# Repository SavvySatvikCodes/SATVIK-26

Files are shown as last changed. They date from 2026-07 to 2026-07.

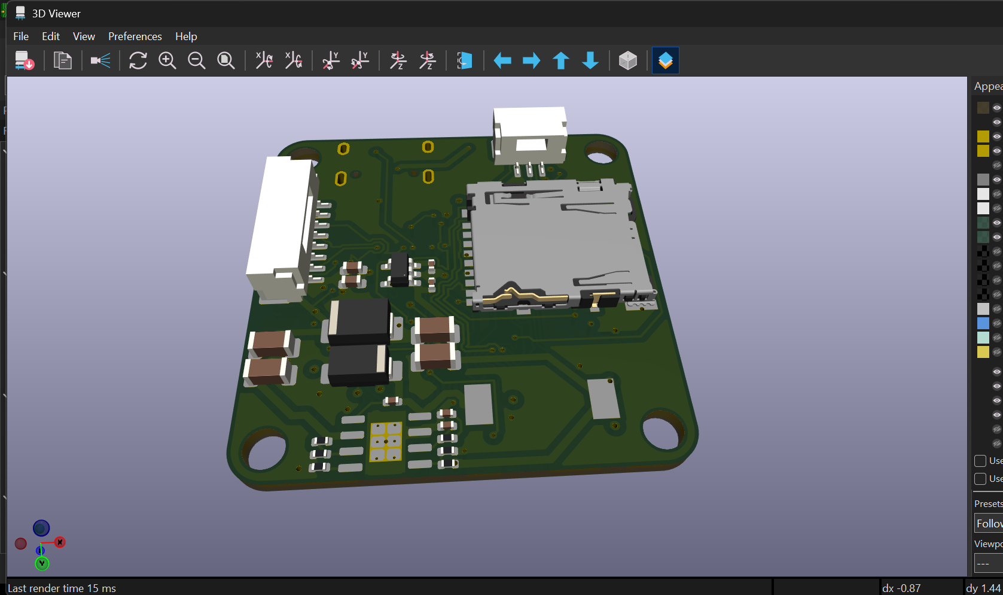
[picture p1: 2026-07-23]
hardware/Screenshot 2026-07-23 163646.png

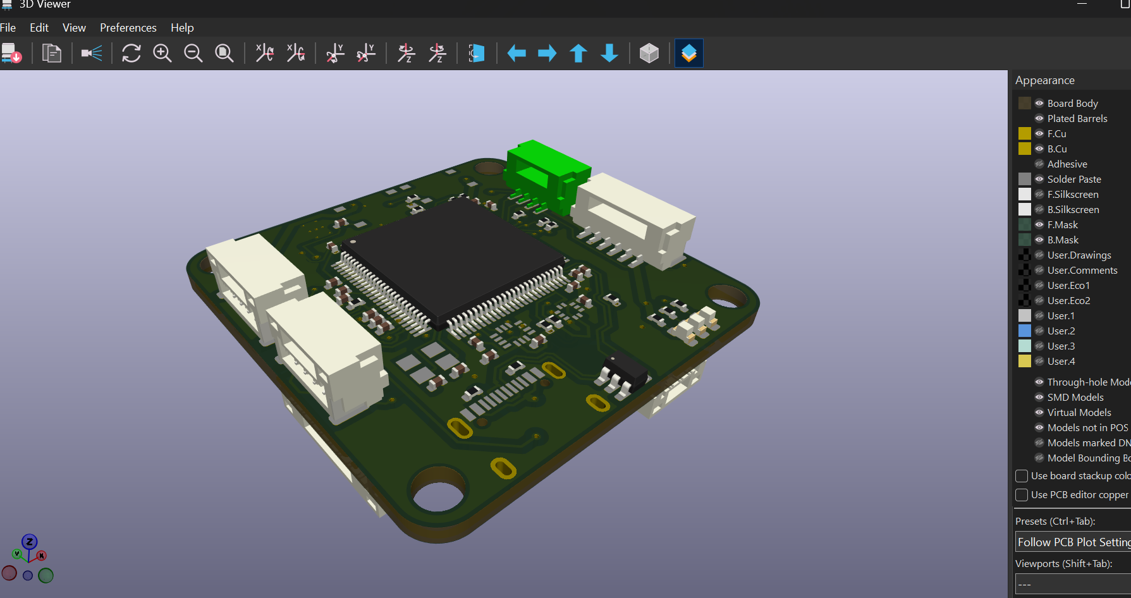
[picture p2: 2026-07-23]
hardware/Screenshot 2026-07-23 163654.png

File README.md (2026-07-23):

# SATVIK-26

**A custom STM32H743 flight controller, designed from scratch for ArduPilot.**

36 × 36 mm, 30.5 mm stack mounting, 4-layer. My first PCB, built for Hack Club Macondo.

---
## What this is

SATVIK-26 is a flight controller: the computer that reads a drone's sensors and decides how fast to spin each motor. It runs [ArduPilot](https://ardupilot.org/) on an STM32H743VIT6, a 480 MHz Cortex-M7.

Anyone can just buy a flight controller and assemble a drone, but I wanted to understand one. There is a large gap between knowing that an IMU talks over Serial Peripheral Interface contrast to having placed that IMU's decoupling capacitor yourself, knowing why it sits exactly where it sits. The only way I know to cross that gap is to draw the schematic and route the board.

This repo is the complete hardware design: schematic, layout, gerbers, BOM, and the reasoning behind the decisions.

---
## Specifications

- MCU - STM32H743VIT6, LQFP-100, 480 MHz Cortex-M7, 2 MB flash/1 MB RAM
- IMU	- ICM-42688-P (TDK InvenSense), SPI1
- Barometer - BMP388 (Bosch), I2C2
- Storage - microSD on SDMMC1 for onboard logging
- USB-C with USBLC6-2SC6 ESD protection, DFU accessible
- Input - 2 to 6S direct battery, SMBJ26A TVS clamp
- 5 V rail - TPS54560 buck, 15 µH inductor, SS56 catch diode
- 3.3 V rail - AP2112K-3.3 LDO from the 5 V rail
- Sensing - VBAT divider and ESC current sense into ADC1
- Motor outputs - 8 PWM channels
- Serial - 6 UARTs on JST-GH connectors
- Board - 36 × 36 mm, 4-layer FR4, 1.6 mm, 3 mm corner radius
- Mounting - 4 × M3 at 30.5 mm (standard FC stack)
- Components - 80 footprints, 55 top and 25 bottom
- Weight - 40 g

---
## What makes this not a copy

**Dual airframe, 8 PWM outputs.** Most 5-inch quad boards break out four motor outputs. I mapped eight timer channels to headers so the same board can fly a quad now and a fixed-wing later, where you need servo channels for ailerons, elevator and rudder on top of throttle. Four outputs would have made this a dead end. Eight cost me real routing space on a 36 mm board, and I decided the flexibility was worth it.

**FPV designed in, not bolted on.** A dedicated UART is broken out for a video transmitter, and the 5 V rail is sized with headroom to feed a camera and VTX rather than just flight electronics. Retrofitting FPV onto a board that never planned for it means splicing into power and hunting for a spare serial port.

**A custom ArduPilot hwdef.** ArduPilot does not know what is wired where on a board it has never seen. I am writing a `hwdef.dat` describing every peripheral, pin function and timer assignment, and the build system compiles firmware specifically for your hardware. That port is part of this project. The board is not finished until it boots real firmware.

For the record: Macondo's flight controller guide builds a **rocket** FC on a different MCU with a battery charger IC. This is a drone FC on an H7, no charger, different power tree, different sensors.

---
## Design decisions

- **TPS54560 buck, rated to 60V.** On 4S that looks like overkill, and cheaper 28 V parts would work. I took the headroom deliberately. 6S is 25.2 V charged, uncomfortably close to a 28 V absolute maximum, and a motor decelerating hard dumps energy back into the rail.
- **Entire power section moved to the back.** I could not route the board with everything on top. Rather than grow it to 40 × 40 and lose stack compatibility, the buck, inductor, LDO, filter caps and thirteen control passives all went to the bottom. That freed the top for MCU fanout, and it put the noisiest thing on the board on the opposite side of a solid ground plane from the IMU, crystal and USB pair. A space fix that turned out to be the right electrical call.
- **IMU as close to the mounting centroid as possible.** The further a sensor sits from the centre of rotation, the more frame vibration it reads as acceleration that is not real. Vibration is the most common cause of bad behaviour in custom ArduPilot builds.
- **Lower KV motors chosen on purpose.** 1855 KV instead of the common 2400 KV. Lower prop RPM means less vibration reaching an IMU sitting on a board I designed myself with no proven mounting. It is also more efficient, which buys flight time. 2400 KV would give roughly 9:1 thrust-to-weight, which is race-quad territory and pointless for a GPS platform flying Loiter and Auto. It also makes tuning the IMU harder.

---
## Stackup
Four layers: **F.Cu** signal, **In1.Cu** GND plane, **In2.Cu** +3V3 plane, **B.Cu** signal and power section.

+3V3 touches 38 pads spread across the whole board. The net that is everywhere gets the plane. VBAT_RAW became short traces, which is all a local 8-pad net needs.

---
## The work

The tidy version above is not how it felt.
Placing components looks like the easy part. It is not. Almost anything fits on a board if all you care about is fitting. I built layouts that passed every clearance check and were physically impossible to route, with pads jammed against the board edge and no path out at all. Each one had to be scrapped and rebuilt.

The final routing push ran **18 hours straight, 1pm on July 22nd to 6am on July 23rd, without a break.** By the end: 1114 track segments, 89 vias, zero unconnected pads.

Some NotSoFun blunders:
- The IMU had been deleted from the board entirely, and I had not noticed
- The crystal had been deleted too
- Thirteen buck and LDO support components stranded on the wrong side after the power flip, meaning a switching regulator's feedback network would have had to via across the board
- A netclass rule silently matching nothing, so every "power" trace was drawing at 0.2 mm instead of 0.6 mm

AND YES... after so much work it is quite nail-biting to put it on JLCPCB to see if your work actually computes... the real test is still far off 

---

## Things I got wrong

- **Connector pin order.** My connectors run 5V, GND, TX, RX. Most off-the-shelf GPS modules and telemetry radios use Pixhawk order with ground on the _last_ pin. Stock cables do not line up, and plugging one in without checking could push 5 V into a UART pin. Fixable by re-pinning cables, so the board still works as designed, but it is a genuine mistake and first on the rev 2 list. Every cable gets continuity-tested before it goes anywhere near power.
- **Thermal reliefs on the ground pours.** Ground connected to pads through four thin spokes, which exists to stop the plane wicking heat away during _hand_ soldering. On a dense board several pads could not fit the minimum spoke count. This board is reflow assembled, so thermal relief was simply the wrong setting. Switched to solid, which is better electrically and thermally.
- **Traces do not follow components.** Move a part after routing and the copper stays behind, silently disconnected. I found this out by doing it. Placement gets finished properly before routing starts.

---
## What I would do differently

- **Stop designing version one like it is the last version.** Most of my pain came from trying to make the first board complete instead of making it _work_. A first revision exists to prove the core design is sound and to teach you what you got wrong. Every extra feature is another thing that can be wrong, and another thing you have to route.
- **Smaller connectors.** JST-GH is the right professional choice and it is what real flight controllers use, but it is physically large and it ate a serious amount of board edge and routing space on a 36 mm board. On a first iteration I would take something more compact, or simply break out fewer UARTs.
- **Skip the gimmicks.** Status LEDs and their resistors, extra headers, nice-to-haves. None of them made the board work. All of them competed for space against things that did.
- **Plan the escape routes before finalizing placement.** The lesson that cost the most time. A component is not placed correctly just because it fits and clears its neighbours. It is placed correctly when every one of its pads has a realistic path to where it needs to go.

---
## Airframe and flight dynamics

| Item | Mass |
| --- | --- |
| 5-inch carbon frame | 120 g |
| 4 × 2207 motors | 132 g |
| 4-in-1 ESC | 14 g |
| SATVIK-26 FC | 40 g |
| GPS, compass, mast | 18 g |
| RC receiver | 15 g |
| Telemetry radio (air) | 15 g |
| Propellers | 18 g |
| Wiring, standoffs, hardware | 35 g |
| **Dry** | **407 g**  |
| 4S 1850 mAh LiPo | 244 g |
| **All-up weight** | **~651 g** |
| | |
___
## Airframe parts

| Part | Chosen component |
| --- | --- |
| Frame | TBS Source One V6, 5 inch |
| Motors | iFlight XING2 2207 1855 KV (×4) |
| ESC | Sequre Blueson A2 6S 65A, AM32 |
| Propellers | Gemfan 51466 tri-blade, 5 inch |
| GPS and compass | Sequre M10-252Q with QMC5883 |
| Telemetry | Micoair 915 MHz LoRa pair |
| RC link | FlySky FS-i6X with FS-iA6B receiver |
| Battery | GNB 1850 mAh 4S 120C, XT60 (×2) |
| FC mounting | Rubber or TPU soft mounts |
With XING2 2207 1855 KV motors on 4S: roughly **6.8:1 thrust-to-weight**, hover throttle around **38 %**, estimated **5-8 minutes** of mixed GPS flying.

---
## Status

- [x] Schematic complete, ERC clean
- [x] Component placement
- [x] 4-layer routing complete, 0 unconnected pads
- [x] DRC clean
- [x] Gerbers verified in JLCPCB's viewer
- [x] BOM and pick-and-place prepared
- [ ] Boards ordered
- [ ] ArduPilot `hwdef` written and firmware compiled
- [ ] Bring-up
- [ ] Airframe assembly
- [ ] Maiden hover
- [ ] Loiter and Auto missions

**Bring-up is planned in order:** visual inspection, then a current-limited bench supply with the limit set low, then every rail verified with a multimeter before a battery touches the board, then USB enumeration and DFU, then flash ArduPilot, then confirm each peripheral in Mission Planner one at a time. Motors tested with **propellers removed**.

---
## Regulatory
Over 250 g, so under Transport Canada rules this must be registered and flown by a certified pilot. That means you (& I) am taking the Small Basic Exam and registering the aircraft.

Basic certification allows uncontrolled (Class G) airspace only, 30 m from bystanders, below 400 ft, within visual line of sight. Most of Toronto is controlled airspace, which needs Advanced certification and a manufacturer safety-assurance declaration, something a homebuilt aircraft cannot obtain by definition. So fly out of city, many apps show you the proper zones.

---
## Tools

**[KiCad 10](https://www.kicad.org/)** for schematic and layout. **[STM32CubeMX](https://www.st.com/en/development-tools/stm32cubemx.html)** for pin mapping. [**ArduPilot**](https://ardupilot.org/) as target firmware, with SITL for development during parts lead time. **[JLCPCB](https://jlcpcb.com/)** for 4-layer fabrication and assembly.

---
CREDITS TO [OBSIDIAN](https://obsidian.md/), an .md file editor and notes taking app, for easing the process of writing in this file format.

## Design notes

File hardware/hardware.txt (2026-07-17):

Configuration	hardware
STM32CubeMX 	6.18.0
Date	07/16/2026
MCU	STM32H743VITx

PERIPHERALS	MODES	FUNCTIONS	PINS
ADC1	IN10 Single-ended	ADC1_INP10	PC0
ADC1	IN11 Single-ended	ADC1_INP11	PC1
I2C2	I2C	I2C2_SCL	PB10
I2C2	I2C	I2C2_SDA	PB11
RCC	Crystal/Ceramic Resonator	RCC_OSC_IN	PH0-OSC_IN (PH0)
RCC	Crystal/Ceramic Resonator	RCC_OSC_OUT	PH1-OSC_OUT (PH1)
SDMMC1	SD 4 bits Wide bus	SDMMC1_CK	PC12
SDMMC1	SD 4 bits Wide bus	SDMMC1_CMD	PD2
SDMMC1	SD 4 bits Wide bus	SDMMC1_D0	PC8
SDMMC1	SD 4 bits Wide bus	SDMMC1_D1	PC9
SDMMC1	SD 4 bits Wide bus	SDMMC1_D2	PC10
SDMMC1	SD 4 bits Wide bus	SDMMC1_D3	PC11
SPI1	Full-Duplex Master	SPI1_MISO	PA6
SPI1	Full-Duplex Master	SPI1_MOSI	PA7
SPI1	Full-Duplex Master	SPI1_SCK	PA5
SYS	SysTick	SYS_VS_Systick	VP_SYS_VS_Systick
TIM3	PWM Generation CH3	TIM3_CH3	PB0
TIM3	PWM Generation CH4	TIM3_CH4	PB1
TIM5	PWM Generation CH1	TIM5_CH1	PA0
TIM5	PWM Generation CH2	TIM5_CH2	PA1
UART4	Asynchronous	UART4_RX	PB8
UART4	Asynchronous	UART4_TX	PB9
UART7	Asynchronous	UART7_RX	PE7
UART7	Asynchronous	UART7_TX	PE8
USART1	Asynchronous	USART1_RX	PA10
USART1	Asynchronous	USART1_TX	PA9
USART2	Asynchronous	USART2_RX	PD6
USART2	Asynchronous	USART2_TX	PD5
USART6	Asynchronous	USART6_RX	PC7
USART6	Asynchronous	USART6_TX	PC6
USB_OTG_FS	Device_Only	USB_OTG_FS_DM	PA11
USB_OTG_FS	Device_Only	USB_OTG_FS_DP	PA12

Pin Nb	PINs	FUNCTIONs	LABELs
9	PC15-OSC32_OUT (OSC32_OUT)	GPIO_Output	
12	PH0-OSC_IN (PH0)	RCC_OSC_IN	
13	PH1-OSC_OUT (PH1)	RCC_OSC_OUT	
15	PC0	ADC1_INP10	
16	PC1	ADC1_INP11	
22	PA0	TIM5_CH1	
23	PA1	TIM5_CH2	
29	PA5	SPI1_SCK	
30	PA6	SPI1_MISO	
31	PA7	SPI1_MOSI	
34	PB0	TIM3_CH3	
35	PB1	TIM3_CH4	
37	PE7	UART7_RX	
38	PE8	UART7_TX	
46	PB10	I2C2_SCL	
47	PB11	I2C2_SDA	
63	PC6	USART6_TX	
64	PC7	USART6_RX	
65	PC8	SDMMC1_D0	
66	PC9	SDMMC1_D1	
68	PA9	USART1_TX	
69	PA10	USART1_RX	
70	PA11	USB_OTG_FS_DM	
71	PA12	USB_OTG_FS_DP	
72	PA13 (JTMS/SWDIO)*	DEBUG_JTMS-SWDIO	
76	PA14 (JTCK/SWCLK)*	DEBUG_JTCK-SWCLK	
78	PC10	SDMMC1_D2	
79	PC11	SDMMC1_D3	
80	PC12	SDMMC1_CK	
83	PD2	SDMMC1_CMD	
86	PD5	USART2_TX	
87	PD6	USART2_RX	
95	PB8	UART4_RX	
96	PB9	UART4_TX	
PERIPHERALS	MODES	FUNCTIONS	PINS
ADC1	IN10 Single-ended	ADC1_INP10	PC0
ADC1	IN11 Single-ended	ADC1_INP11	PC1
I2C2	I2C	I2C2_SCL	PB10
I2C2	I2C	I2C2_SDA	PB11
RCC	Crystal/Ceramic Resonator	RCC_OSC_IN	PH0-OSC_IN (PH0)
RCC	Crystal/Ceramic Resonator	RCC_OSC_OUT	PH1-OSC_OUT (PH1)
SDMMC1	SD 4 bits Wide bus	SDMMC1_CK	PC12
SDMMC1	SD 4 bits Wide bus	SDMMC1_CMD	PD2
SDMMC1	SD 4 bits Wide bus	SDMMC1_D0	PC8
SDMMC1	SD 4 bits Wide bus	SDMMC1_D1	PC9
SDMMC1	SD 4 bits Wide bus	SDMMC1_D2	PC10
SDMMC1	SD 4 bits Wide bus	SDMMC1_D3	PC11
SPI1	Full-Duplex Master	SPI1_MISO	PA6
SPI1	Full-Duplex Master	SPI1_MOSI	PA7
SPI1	Full-Duplex Master	SPI1_SCK	PA5
SYS	SysTick	SYS_VS_Systick	VP_SYS_VS_Systick
TIM3	PWM Generation CH3	TIM3_CH3	PB0
TIM3	PWM Generation CH4	TIM3_CH4	PB1
TIM5	PWM Generation CH1	TIM5_CH1	PA0
TIM5	PWM Generation CH2	TIM5_CH2	PA1
UART4	Asynchronous	UART4_RX	PB8
UART4	Asynchronous	UART4_TX	PB9
UART7	Asynchronous	UART7_RX	PE7
UART7	Asynchronous	UART7_TX	PE8
USART1	Asynchronous	USART1_RX	PA10
USART1	Asynchronous	USART1_TX	PA9
USART2	Asynchronous	USART2_RX	PD6
USART2	Asynchronous	USART2_TX	PD5
USART6	Asynchronous	USART6_RX	PC7
USART6	Asynchronous	USART6_TX	PC6
USB_OTG_FS	Device_Only	USB_OTG_FS_DM	PA11
USB_OTG_FS	Device_Only	USB_OTG_FS_DP	PA12

Pin Nb	PINs	FUNCTIONs	LABELs
9	PC15-OSC32_OUT (OSC32_OUT)	GPIO_Output	
12	PH0-OSC_IN (PH0)	RCC_OSC_IN	
13	PH1-OSC_OUT (PH1)	RCC_OSC_OUT	
15	PC0	ADC1_INP10	
16	PC1	ADC1_INP11	
22	PA0	TIM5_CH1	
23	PA1	TIM5_CH2	
29	PA5	SPI1_SCK	
30	PA6	SPI1_MISO	
31	PA7	SPI1_MOSI	
34	PB0	TIM3_CH3	
35	PB1	TIM3_CH4	
37	PE7	UART7_RX	
38	PE8	UART7_TX	
46	PB10	I2C2_SCL	
47	PB11	I2C2_SDA	
63	PC6	USART6_TX	
64	PC7	USART6_RX	
65	PC8	SDMMC1_D0	
66	PC9	SDMMC1_D1	
68	PA9	USART1_TX	
69	PA10	USART1_RX	
70	PA11	USB_OTG_FS_DM	
71	PA12	USB_OTG_FS_DP	
72	PA13 (JTMS/SWDIO)*	DEBUG_JTMS-SWDIO	
76	PA14 (JTCK/SWCLK)*	DEBUG_JTCK-SWCLK	
78	PC10	SDMMC1_D2	
79	PC11	SDMMC1_D3	
80	PC12	SDMMC1_CK	
83	PD2	SDMMC1_CMD	
86	PD5	USART2_TX	
87	PD6	USART2_RX	
95	PB8	UART4_RX	
96	PB9	UART4_TX	

SOFTWARE PROJECT

Project Settings : 
Project Name : hardware
Project Folder : C:\Users\gargs\Desktop\SavvyVenv\GITTY\SATVIK-26\hardware
Toolchain / IDE : EWARM V8.50
Firmware Package Name and Version : STM32Cube FW_H7 V1.13.0

Code Generation Settings : 
STM32Cube MCU packages and embedded software packs : Copy all used libraries into the project folder
Generate peripheral initialization as a pair of '.c/.h' files per peripheral : No
Backup previously generated files when re-generating : No
Delete previously generated files when not re-generated : Yes
Set all free pins as analog (to optimize the power consumption) : No

Toolchains Settings : 
Compiler Optimizations :

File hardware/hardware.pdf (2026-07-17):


16/07/2026

hardware Project
Configuration Report

## 1. Description

### 1.1. Project

Project Name | hardware
Board Name | custom
Generated with: | STM32CubeMX 6.18.0
Date | 07/16/2026

### 1.2. MCU

MCU Series | STM32H7
MCU Line | STM32H743/753
MCU name | STM32H743VITx
MCU Package | LQFP100
MCU Pin number | 100

### 1.3. Core(s) information

Core(s) | ARM Cortex-M7

## 2. Pinout Configuration

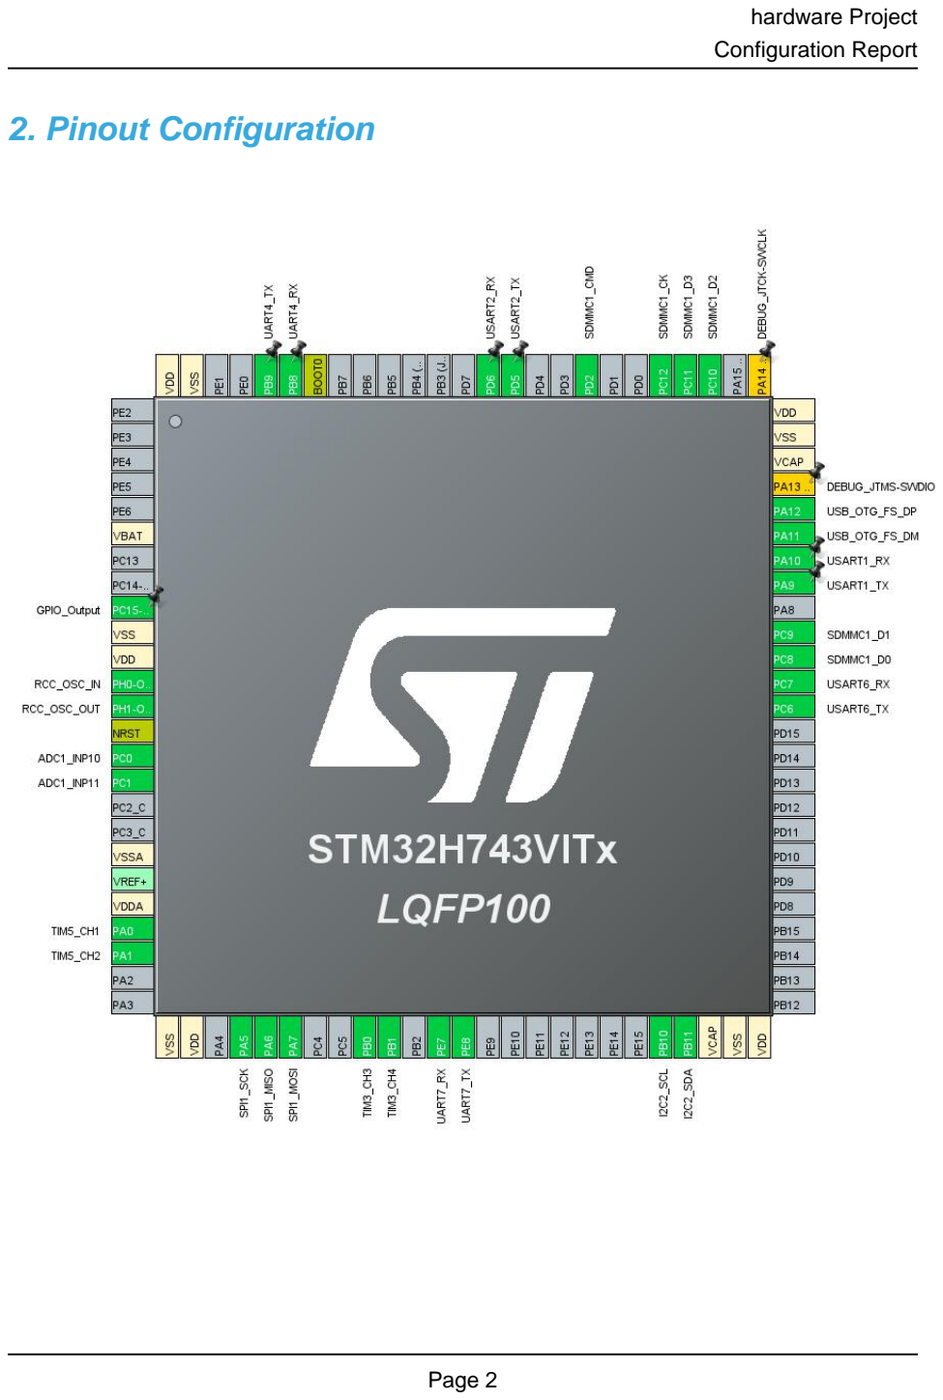
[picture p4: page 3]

## 3. Pins Configuration

Pin Number LQFP100 | Pin Name (function after reset) | Pin Type | Alternate Function(s) | Label
6 | VBAT | Power
9 | PC15-OSC32_OUT (OSC32_OUT) * | I/O | GPIO_Output
10 | VSS | Power
11 | VDD | Power
12 | PH0-OSC_IN (PH0) | I/O | RCC_OSC_IN
13 | PH1-OSC_OUT (PH1) | I/O | RCC_OSC_OUT
14 | NRST | Reset
15 | PC0 | I/O | ADC1_INP10
16 | PC1 | I/O | ADC1_INP11
19 | VSSA | Power
21 | VDDA | Power
22 | PA0 | I/O | TIM5_CH1
23 | PA1 | I/O | TIM5_CH2
26 | VSS | Power
27 | VDD | Power
29 | PA5 | I/O | SPI1_SCK
30 | PA6 | I/O | SPI1_MISO
31 | PA7 | I/O | SPI1_MOSI
34 | PB0 | I/O | TIM3_CH3
35 | PB1 | I/O | TIM3_CH4
37 | PE7 | I/O | UART7_RX
38 | PE8 | I/O | UART7_TX
46 | PB10 | I/O | I2C2_SCL
47 | PB11 | I/O | I2C2_SDA
48 | VCAP | Power
49 | VSS | Power
50 | VDD | Power
63 | PC6 | I/O | USART6_TX
64 | PC7 | I/O | USART6_RX
65 | PC8 | I/O | SDMMC1_D0
66 | PC9 | I/O | SDMMC1_D1
68 | PA9 | I/O | USART1_TX
69 | PA10 | I/O | USART1_RX
70 | PA11 | I/O | USB_OTG_FS_DM
71 | PA12 | I/O | USB_OTG_FS_DP

Pin Number LQFP100 | Pin Name (function after reset) | Pin Type | Alternate Function(s) | Label
72 | PA13 (JTMS/SWDIO) ** | I/O | DEBUG_JTMS-SWDIO
73 | VCAP | Power
74 | VSS | Power
75 | VDD | Power
76 | PA14 (JTCK/SWCLK) ** | I/O | DEBUG_JTCK-SWCLK
78 | PC10 | I/O | SDMMC1_D2
79 | PC11 | I/O | SDMMC1_D3
80 | PC12 | I/O | SDMMC1_CK
83 | PD2 | I/O | SDMMC1_CMD
86 | PD5 | I/O | USART2_TX
87 | PD6 | I/O | USART2_RX
94 | BOOT0 | Boot
95 | PB8 | I/O | UART4_RX
96 | PB9 | I/O | UART4_TX
99 | VSS | Power
100 | VDD | Power

* The pin is affected with an I/O function
** The pin is affected with a peripheral function but no peripheral mode is activated

## 4. Clock Tree Configuration

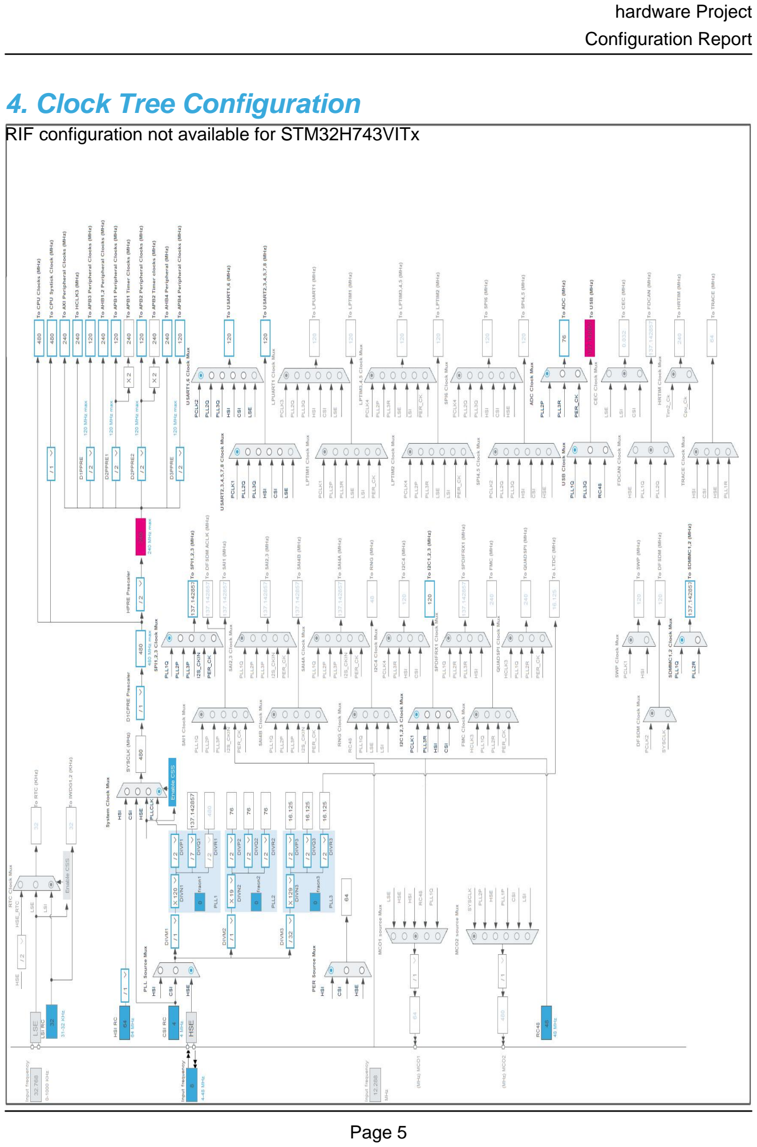
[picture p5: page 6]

RIF configuration not available for STM32H743VITx

## 1. Power Consumption Calculator report

### 1.1. Microcontroller Selection

Series | STM32H7
Line | STM32H743/753
MCU | STM32H743VITx
Datasheet | DS12110_Rev8

### 1.2. Parameter Selection

Temperature | 25
Vdd | 3.0

### 1.3. Battery Selection

Battery | Alkaline(9V)
Capacity | 625.0 mAh
Self Discharge | 0.3 %/month
Nominal Voltage | 9.0 V
Max Cont Current | 200.0 mA
Max Pulse Current | 0.0 mA
Cells in series | 1
Cells in parallel | 1

### 1.4. Sequence

Step | Step1 | Step2
Mode | RUN | STOP
Vdd | 3.0 | 3.0
Voltage Source | Battery | Battery
Range | VOS0: Scale0-High | SVOS5: System-Scale5
D1 Mode | DRUN/CRUN | DSTANDBY
D2 Mode | DRUN | DSTANDBY
D3 Mode | DRUN | DSTOP
Fetch Type | ITCM | NA
CPU Frequency | 480 MHz | 0 Hz
Clock Configuration | HSE BYP PLL | Flash-OFF
Clock Source Frequency | 24 MHz | 0 Hz
Peripherals
Additional Cons. | 0 mA | 0 mA
Average Current | 148 mA | 150 µA
Duration | 0.1 ms | 0.9 ms
DMIPS | 1027.0 | 0.0
Ta Max | 105.02 | 124.98
Category | In DS Table | In DS Table

### 1.5. Results

Sequence Time | 1 ms | Average Current | 14.94 mA
Battery Life | 1 day, 17 hours | Average DMIPS | 1027.2001 DMIPS

### 1.6. Chart

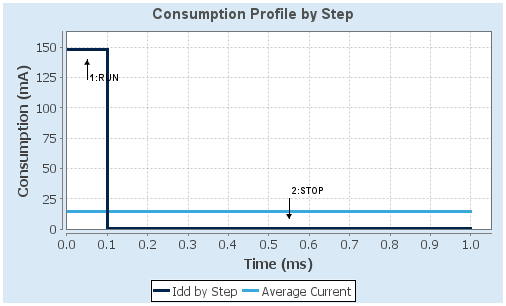
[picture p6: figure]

## 2. Software Project

### 2.1. Project Settings

Name | Value
Project Name | hardware
Project Folder | C:\Users\gargs\Desktop\SavvyVenv\GITTY\SATVIK-26\hardware
Toolchain / IDE | EWARM V8.50
Firmware Package Name and Version | STM32Cube FW_H7 V1.13.0
Application Structure | Advanced
Generate Under Root | No
Do not generate the main() | No
Minimum Heap Size | 0x200
Minimum Stack Size | 0x400

### 2.2. Code Generation Settings

Name | Value
STM32Cube MCU packages and embedded software | Copy all used libraries into the project folder
Generate peripheral initialization as a pair of '.c/.h' files | No
Backup previously generated files when re-generating | No
Keep User Code when re-generating | Yes
Delete previously generated files when not re-generated | Yes
Set all free pins as analog (to optimize the power consumption) | No
Enable Full Assert | No

### 2.3. Advanced Settings - Generated Function Calls

Rank | Function Name | Peripheral Instance Name
1 | SystemClock_Config | RCC
2 | MX_GPIO_Init | GPIO
3 | MX_SPI1_Init | SPI1
4 | MX_USB_OTG_FS_PCD_Init | USB_OTG_FS
5 | MX_ADC1_Init | ADC1
6 | MX_I2C2_Init | I2C2
7 | MX_SDMMC1_SD_Init | SDMMC1
8 | MX_TIM3_Init | TIM3
9 | MX_TIM5_Init | TIM5
10 | MX_UART4_Init | UART4
11 | MX_UART7_Init | UART7

Rank | Function Name | Peripheral Instance Name
12 | MX_USART1_UART_Init | USART1
13 | MX_USART2_UART_Init | USART2
14 | MX_USART6_UART_Init | USART6

## 3. Peripherals and Middlewares Configuration

### 3.1. ADC1

IN10: IN10 Single-ended
mode: IN11
3.1.1. Parameter Settings:

ADCs_Common_Settings:

Mode | Independent mode
ADC_Settings:
Clock Prescaler | Asynchronous clock mode divided by 1
Resolution | ADC 16-bit resolution
Scan Conversion Mode | Disabled
Continuous Conversion Mode | Disabled
Discontinuous Conversion Mode | Disabled
End Of Conversion Selection | End of single conversion
Overrun behaviour | Overrun data preserved
Left Bit Shift | No bit shift
Conversion Data Management Mode | Regular Conversion data stored in DR register only
Low Power Auto Wait | Disabled
ADC_Regular_ConversionMode:
Enable Regular Conversions | Enable
Enable Regular Oversampling | Disable
Oversampling Ratio | 1
Number Of Conversion | 1
External Trigger Conversion Source | Regular Conversion launched by software
External Trigger Conversion Edge | None
Rank | 1
Channel | Channel 10
Sampling Time | 1.5 Cycles
Offset Number | No offset
Offset Signed Saturation | Disable
ADC_Injected_ConversionMode:
Enable Injected Conversions | Disable
Analog Watchdog 1:
Enable Analog WatchDog1 Mode | false
Analog Watchdog 2:
Enable Analog WatchDog2 Mode | false
Analog Watchdog 3:
Enable Analog WatchDog3 Mode | false

### 3.2. CORTEX_M7

3.2.1. Parameter Settings:

Speculation default mode Settings:

Speculation default mode | Enabled *
Cortex Interface Settings:
CPU ICache | Disabled
CPU DCache | Disabled
Cortex Memory Protection Unit Control Settings:
MPU Control Mode | Background Region Privileged accesses only + MPU Disabled during hard fault, NMI and FAULTMASK handlers

Cortex Memory Protection Unit Region 0 Settings:

MPU Region | Enabled
MPU Region Base Address | 0x0 *
MPU Region Size | 4GB
MPU SubRegion Disable | 0x87 *
MPU TEX field level | level 0
MPU Access Permission | ALL ACCESS NOT PERMITTED
MPU Instruction Access | DISABLE
MPU Shareability Permission | ENABLE
MPU Cacheable Permission | DISABLE
MPU Bufferable Permission | DISABLE
Cortex Memory Protection Unit Region 1 Settings:
MPU Region | Disabled
Cortex Memory Protection Unit Region 2 Settings:
MPU Region | Disabled
Cortex Memory Protection Unit Region 3 Settings:
MPU Region | Disabled
Cortex Memory Protection Unit Region 4 Settings:
MPU Region | Disabled
Cortex Memory Protection Unit Region 5 Settings:
MPU Region | Disabled
Cortex Memory Protection Unit Region 6 Settings:
MPU Region | Disabled
Cortex Memory Protection Unit Region 7 Settings:
MPU Region | Disabled
Cortex Memory Protection Unit Region 8 Settings:

MPU Region | Disabled
Cortex Memory Protection Unit Region 9 Settings:
MPU Region | Disabled
Cortex Memory Protection Unit Region 10 Settings:
MPU Region | Disabled
Cortex Memory Protection Unit Region 11 Settings:
MPU Region | Disabled
Cortex Memory Protection Unit Region 12 Settings:
MPU Region | Disabled
Cortex Memory Protection Unit Region 13 Settings:
MPU Region | Disabled
Cortex Memory Protection Unit Region 14 Settings:
MPU Region | Disabled
Cortex Memory Protection Unit Region 15 Settings:
MPU Region | Disabled

### 3.3. I2C2

I2C: I2C
3.3.1. Parameter Settings:

Timing configuration:

Custom Timing | Disabled
I2C Speed Mode | Standard Mode
I2C Speed Frequency (KHz) | 100
Rise Time (ns) | 0
Fall Time (ns) | 0
Coefficient of Digital Filter | 0
Analog Filter | Enabled
Timing | 0x307075B1 *
Slave Features:
Clock No Stretch Mode | Disabled
General Call Address Detection | Disabled
Primary Address Length selection | 7-bit
Dual Address Acknowledged | Disabled
Primary slave address | 0

### 3.4. MEMORYMAP

mode: Activated

### 3.5. RCC

High Speed Clock (HSE): Crystal/Ceramic Resonator
3.5.1. Parameter Settings:

Power Parameters:

SupplySource | PWR_LDO_SUPPLY
Power Regulator Voltage Scale | Power Regulator Voltage Scale 0
RCC Parameters:
TIM Prescaler Selection | Disabled
HSE Startup Timout Value (ms) | 100
LSE Startup Timout Value (ms) | 5000
CSI Calibration Value | 32
HSI Calibration Value | 64
System Parameters:
VDD voltage (V) | 3.3
Flash Latency(WS) | 4 WS (5 CPU cycle)
Product revision | rev.V
PLL range Parameters:
PLL1 clock Input range | Between 8 and 16 MHz
PLL2 input frequency range | Between 8 and 16 MHz
PLL1 clock Output range | Wide VCO range
PLL2 clock Output range | MEDIUM VCO range

### 3.6. SDMMC1

Mode: SD 4 bits Wide bus
3.6.1. Parameter Settings:

SDMMC parameters:

Clock transition on which the bit capture is made | Rising transition
SDMMC Clock output enable when the bus is idle | Disable the power save for the clock
SDMMC hardware flow control | The hardware control flow is disabled
SDMMC clock divide factor | 0
Is external transceiver present ? | no

### 3.7. SPI1

Mode: Full-Duplex Master
3.7.1. Parameter Settings:

Basic Parameters:

Frame Format | Motorola
Data Size | 4 Bits
First Bit | MSB First
Clock Parameters:
Prescaler (for Baud Rate) | 2
Baud Rate | 68.57143 MBits/s *
Clock Polarity (CPOL) | Low
Clock Phase (CPHA) | 1 Edge
Advanced Parameters:
CRC Calculation | Disabled
NSSP Mode | Enabled
NSS Signal Type | Software
Fifo Threshold | Fifo Threshold 01 Data
Tx Crc Initialization Pattern | All Zero Pattern
Rx Crc Initialization Pattern | All Zero Pattern
Nss Polarity | Nss Polarity Low
Master Ss Idleness | 00 Cycle
Master Inter Data Idleness | 00 Cycle
Master Receiver Auto Susp | Disable
Master Keep Io State | Master Keep Io State Disable
IO Swap | Disabled

### 3.8. SYS

Timebase Source: SysTick

### 3.9. TIM3

Channel3: PWM Generation CH3 Channel4: PWM Generation CH4
3.9.1. Parameter Settings:

Counter Settings:

Prescaler (PSC - 16 bits value) | 0

Counter Mode | Up
Counter Period (AutoReload Register - 16 bits value ) | 65535
Internal Clock Division (CKD) | No Division
auto-reload preload | Disable
Trigger Output (TRGO) Parameters:
Master/Slave Mode (MSM bit) | Disable (Trigger input effect not delayed)
Trigger Event Selection TRGO | Reset (UG bit from TIMx_EGR)
Clear Input:
Clear Input Source | Disable
PWM Generation Channel 3:
Mode | PWM mode 1
Pulse (16 bits value) | 0
Output compare preload | Enable
Fast Mode | Disable
CH Polarity | High
PWM Generation Channel 4:
Mode | PWM mode 1
Pulse (16 bits value) | 0
Output compare preload | Enable
Fast Mode | Disable
CH Polarity | High

### 3.10. TIM5

Channel1: PWM Generation CH1 Channel2: PWM Generation CH2
3.10.1. Parameter Settings:

Counter Settings:

Prescaler (PSC - 16 bits value) | 0
Counter Mode | Up
Counter Period (AutoReload Register - 32 bits value ) | 4294967295
Internal Clock Division (CKD) | No Division
auto-reload preload | Disable
Trigger Output (TRGO) Parameters:
Master/Slave Mode (MSM bit) | Disable (Trigger input effect not delayed)
Trigger Event Selection TRGO | Reset (UG bit from TIMx_EGR)
Clear Input:
Clear Input Source | Disable
PWM Generation Channel 1:

Mode | PWM mode 1
Pulse (32 bits value) | 0
Output compare preload | Enable
Fast Mode | Disable
CH Polarity | High
PWM Generation Channel 2:
Mode | PWM mode 1
Pulse (32 bits value) | 0
Output compare preload | Enable
Fast Mode | Disable
CH Polarity | High

### 3.11. UART4

Mode: Asynchronous
3.11.1. Parameter Settings:

Basic Parameters:

Baud Rate | 115200
Word Length | 8 Bits (including Parity)
Parity | None
Stop Bits | 1
Advanced Parameters:
Data Direction | Receive and Transmit
Over Sampling | 16 Samples
Single Sample | Disable
ClockPrescaler | 1
Fifo Mode | FIFO mode disable
Txfifo Threshold | 1 eighth full configuration
Rxfifo Threshold | 1 eighth full configuration
Advanced Features:
Auto Baudrate | Disable
TX Pin Active Level Inversion | Disable
RX Pin Active Level Inversion | Disable
Data Inversion | Disable
TX and RX Pins Swapping | Disable
Overrun | Enable
DMA on RX Error | Enable
MSB First | Disable

### 3.12. UART7

Mode: Asynchronous
3.12.1. Parameter Settings:

Basic Parameters:

Baud Rate | 115200
Word Length | 8 Bits (including Parity)
Parity | None
Stop Bits | 1
Advanced Parameters:
Data Direction | Receive and Transmit
Over Sampling | 16 Samples
Single Sample | Disable
ClockPrescaler | 1
Fifo Mode | FIFO mode disable
Txfifo Threshold | 1 eighth full configuration
Rxfifo Threshold | 1 eighth full configuration
Advanced Features:
Auto Baudrate | Disable
TX Pin Active Level Inversion | Disable
RX Pin Active Level Inversion | Disable
Data Inversion | Disable
TX and RX Pins Swapping | Disable
Overrun | Enable
DMA on RX Error | Enable
MSB First | Disable

### 3.13. USART1

Mode: Asynchronous
3.13.1. Parameter Settings:

Basic Parameters:

Baud Rate | 115200
Word Length | 8 Bits (including Parity)
Parity | None
Stop Bits | 1
Advanced Parameters:
Data Direction | Receive and Transmit

Over Sampling | 16 Samples
Single Sample | Disable
ClockPrescaler | 1
Fifo Mode | Disable
Txfifo Threshold | 1 eighth full configuration
Rxfifo Threshold | 1 eighth full configuration
Advanced Features:
Auto Baudrate | Disable
TX Pin Active Level Inversion | Disable
RX Pin Active Level Inversion | Disable
Data Inversion | Disable
TX and RX Pins Swapping | Disable
Overrun | Enable
DMA on RX Error | Enable
MSB First | Disable

### 3.14. USART2

Mode: Asynchronous
3.14.1. Parameter Settings:

Basic Parameters:

Baud Rate | 115200
Word Length | 8 Bits (including Parity)
Parity | None
Stop Bits | 1
Advanced Parameters:
Data Direction | Receive and Transmit
Over Sampling | 16 Samples
Single Sample | Disable
ClockPrescaler | 1
Fifo Mode | Disable
Txfifo Threshold | 1 eighth full configuration
Rxfifo Threshold | 1 eighth full configuration
Advanced Features:
Auto Baudrate | Disable
TX Pin Active Level Inversion | Disable
RX Pin Active Level Inversion | Disable
Data Inversion | Disable
TX and RX Pins Swapping | Disable
Overrun | Enable

DMA on RX Error | Enable
MSB First | Disable

### 3.15. USART6

Mode: Asynchronous
3.15.1. Parameter Settings:

Basic Parameters:

Baud Rate | 115200
Word Length | 8 Bits (including Parity)
Parity | None
Stop Bits | 1
Advanced Parameters:
Data Direction | Receive and Transmit
Over Sampling | 16 Samples
Single Sample | Disable
ClockPrescaler | 1
Fifo Mode | Disable
Txfifo Threshold | 1 eighth full configuration
Rxfifo Threshold | 1 eighth full configuration
Advanced Features:
Auto Baudrate | Disable
TX Pin Active Level Inversion | Disable
RX Pin Active Level Inversion | Disable
Data Inversion | Disable
TX and RX Pins Swapping | Disable
Overrun | Enable
DMA on RX Error | Enable
MSB First | Disable

### 3.16. USB_OTG_FS

Mode: Device_Only
3.16.1. Parameter Settings:
Speed | Full Speed 12MBit/s
Enable internal IP DMA | Disabled
Low power | Disabled
Battery charging | Disabled

Link Power Management | Disabled
Use dedicated end point 1 interrupt | Disabled
VBUS sensing | Disabled
Signal start of frame | Disabled

* User modified value

## 4. System Configuration

### 4.1. GPIO configuration

IP | Pin | Signal | GPIO mode | GPIO pull/up pull down

Max
Speed

User Label

ADC1 | PC0 | ADC1_INP10 | Analog mode | No pull-up and no pull-down | n/a
| PC1 | ADC1_INP11 | Analog mode | No pull-up and no pull-down | n/a
I2C2 | PB10 | I2C2_SCL | Alternate Function Open Drain | No pull-up and no pull-down | Low
| PB11 | I2C2_SDA | Alternate Function Open Drain | No pull-up and no pull-down | Low
RCC | PH0- OSC_IN (PH0) | RCC_OSC_IN | n/a | n/a | n/a

PH1-
OSC_OUT
(PH1)
RCC_OSC_OUT | n/a | n/a | n/a
SDMMC1 | PC8 | SDMMC1_D0 | Alternate Function Push Pull | No pull-up and no pull-down | Very High
| PC9 | SDMMC1_D1 | Alternate Function Push Pull | No pull-up and no pull-down | Very High
| PC10 | SDMMC1_D2 | Alternate Function Push Pull | No pull-up and no pull-down | Very High
| PC11 | SDMMC1_D3 | Alternate Function Push Pull | No pull-up and no pull-down | Very High
PC12 | SDMMC1_CK Alternate Function Push Pull | No pull-up and no pull-down | Very High
PD2 | SDMMC1_CMD Alternate Function Push Pull | No pull-up and no pull-down | Very High
SPI1 | PA5 | SPI1_SCK | Alternate Function Push Pull | No pull-up and no pull-down | Low
| PA6 | SPI1_MISO | Alternate Function Push Pull | No pull-up and no pull-down | Low
| PA7 | SPI1_MOSI | Alternate Function Push Pull | No pull-up and no pull-down | Low
TIM3 | PB0 | TIM3_CH3 | Alternate Function Push Pull | No pull-up and no pull-down | Low
| PB1 | TIM3_CH4 | Alternate Function Push Pull | No pull-up and no pull-down | Low
TIM5 | PA0 | TIM5_CH1 | Alternate Function Push Pull | No pull-up and no pull-down | Low
| PA1 | TIM5_CH2 | Alternate Function Push Pull | No pull-up and no pull-down | Low
UART4 | PB8 | UART4_RX | Alternate Function Push Pull | No pull-up and no pull-down | Low
| PB9 | UART4_TX | Alternate Function Push Pull | No pull-up and no pull-down | Low
UART7 | PE7 | UART7_RX | Alternate Function Push Pull | No pull-up and no pull-down | Low
| PE8 | UART7_TX | Alternate Function Push Pull | No pull-up and no pull-down | Low
USART1 | PA9 | USART1_TX | Alternate Function Push Pull | No pull-up and no pull-down | Low
| PA10 | USART1_RX | Alternate Function Push Pull | No pull-up and no pull-down | Low
USART2 | PD5 | USART2_TX | Alternate Function Push Pull | No pull-up and no pull-down | Low
| PD6 | USART2_RX | Alternate Function Push Pull | No pull-up and no pull-down | Low
USART6 | PC6 | USART6_TX | Alternate Function Push Pull | No pull-up and no pull-down | Low
| PC7 | USART6_RX | Alternate Function Push Pull | No pull-up and no pull-down | Low
USB_OTG_ FS | PA11 | USB_OTG_FS_ DM | Alternate Function Push Pull | No pull-up and no pull-down | Low
| PA12 | USB_OTG_FS_ | Alternate Function Push Pull | No pull-up and no pull-down | Low

IP | Pin | Signal | GPIO mode | GPIO pull/up pull down | Max Speed | User Label
| | DP
Single Mapped Signals | PA13 (JTMS/SWDI O) | DEBUG_JTMS-SWDIO | n/a | n/a | n/a
| PA14 (JTCK/SWC LK) | DEBUG_JTCK-SWCLK | n/a | n/a | n/a
GPIO | PC15-OSC32_OU T | GPIO_Output | Output Push Pull | No pull-up and no pull-down | Low

### 4.2. DMA configuration

nothing configured in DMA service

### 4.3. BDMA configuration

nothing configured in DMA service

### 4.4. MDMA configuration

nothing configured in DMA service

### 4.5. NVIC configuration

4.5.1. NVIC
Interrupt Table | Enable | Preenmption Priority | SubPriority
Non maskable interrupt | true | 0 | 0
Hard fault interrupt | true | 0 | 0
Memory management fault | true | 0 | 0
Pre-fetch fault, memory access fault | true | 0 | 0
Undefined instruction or illegal state | true | 0 | 0
System service call via SWI instruction | true | 0 | 0
Debug monitor | true | 0 | 0
Pendable request for system service | true | 0 | 0
System tick timer | true | 15 | 0
PVD and AVD interrupts through EXTI line 16 | | unused
Flash global interrupt | | unused
RCC global interrupt | | unused
ADC1 and ADC2 global interrupts | | unused
TIM3 global interrupt | | unused
I2C2 event interrupt | | unused
I2C2 error interrupt | | unused
SPI1 global interrupt | | unused
USART1 global interrupt | | unused
USART2 global interrupt | | unused
SDMMC1 global interrupt | | unused
TIM5 global interrupt | | unused
UART4 global interrupt | | unused
USART6 global interrupt | | unused
FPU global interrupt | | unused
UART7 global interrupt | | unused
USB On The Go FS End Point 1 Out global interrupt | | unused
USB On The Go FS End Point 1 In global interrupt | | unused
USB OTG FS global interrupt | | unused
HSEM1 global interrupt | | unused
4.5.2. NVIC Code generation

Enabled interrupt Table Select for init
sequence ordering
| | Generate IRQ
| | handler | Call HAL handler
Non maskable interrupt | false | true | false
Hard fault interrupt | false | true | false

Enabled interrupt Table | Select for init sequence ordering | Generate IRQ handler | Call HAL handler
Memory management fault | false | true | false
Pre-fetch fault, memory access fault | false | true | false
Undefined instruction or illegal state | false | true | false
System service call via SWI instruction | false | true | false
Debug monitor | false | true | false
Pendable request for system service | false | true | false
System tick timer | false | true | true

* User modified value

## 5. System Views

5.1. Category view
5.1.1. Current

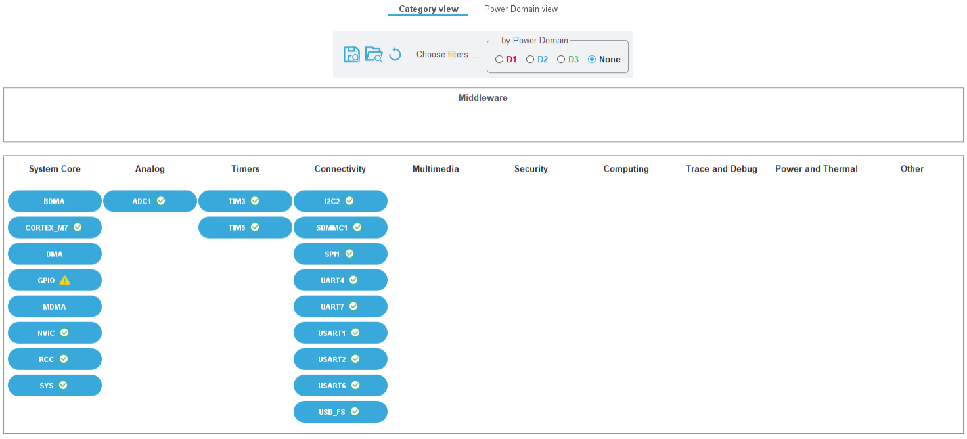
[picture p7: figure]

5.1.2. Without filters

5.2. Power Domain view

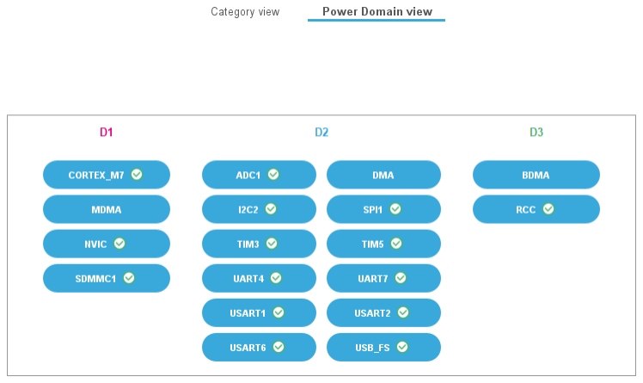
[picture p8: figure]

## 6. Docs & Resources

Type | Link
BSDL files | https://www.st.com/resource/en/bsdl_model/stm32h7-bsdl.zip
IBIS models | https://www.st.com/resource/en/ibis_model/stm32h7_ibis.zip
System View Description | https://www.st.com/resource/en/svd/stm32h7-svd.zip
Presentations | https://www.st.com/resource/en/product_presentation/microcontrollers_stm32h7_series_product_overview.pdf
Presentations | https://www.st.com/resource/en/product_presentation/stm32-stm8_embedded_software_solutions.pdf
Presentations | https://www.st.com/resource/en/product_presentation/stm32_eval-tools_portfolio.pdf
Presentations | https://www.st.com/resource/en/product_presentation/stm32_stm8_functi onal-safety-packages.pdf
Presentations | https://www.st.com/resource/en/product_presentation/stm32-stm8_software_development_tools.pdf
Presentations | https://www.st.com/resource/en/product_presentation/microcontrollers-stm32-family-overview.pdf
Presentations | https://www.st.com/resource/en/product_presentation/microcontrollers-stm32h7rs-lines-overview.pdf
Brochures | https://www.st.com/resource/en/brochure/brstm32h7.pdf
Brochures | https://www.st.com/resource/en/brochure/humanoid-robot-reference-guide.pdf
Flyers | https://www.st.com/resource/en/flyer/flstm32nucleo.pdf
Flyers | https://www.st.com/resource/en/flyer/flstm32trust.pdf
Flyers | https://www.st.com/resource/en/flyer/flpowerstbd.pdf
Flyers | https://www.st.com/resource/en/flyer/flstm32h7rs.pdf
Security Bulletin | https://www.st.com/resource/en/technical_note/tn1489-security-bulletin-tn1489stpsirt-physical-attacks-on-stm32-and-stm32cube-firmware-stmicroelectronics.pdf
Security Bulletin | https://www.st.com/resource/en/security_bulletin/sb0023-eucleak-

| protection-statement-for-stmicroelectronics-certified-products-stmicroelectronics.pdf
Application Notes | https://www.st.com/resource/en/application_note/an1709-emc-design-guide-for-stm8-stm32-and-legacy-mcus-stmicroelectronics.pdf
Application Notes | https://www.st.com/resource/en/application_note/an4221-i2c-protocol-used-in-the-stm32-bootloader-stmicroelectronics.pdf
Application Notes | https://www.st.com/resource/en/application_note/an4539-hrtim-cookbook-stmicroelectronics.pdf
Application Notes | https://www.st.com/resource/en/application_note/an4655-virtually-increasing-the-number-of-serial-communication-peripherals-in-stm32-applications-stmicroelectronics.p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
Application Notes | https://www.st.com/resource/en/application_note/an4750-handling-of-soft-errors-in-stm32-applications-stmicroelectronics.pdf
Application Notes | https://www.st.com/resource/en/application_note/an4803-highspeed-si-simulations-using-ibis-and-boardlevel-simulations-using-hyperlynx-si-on-stm32-mcus-and-mpus-stmic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
Application Notes | https://www.st.com/resource/en/application_note/an4839-level-1-cache-on-stm32f7-series-and-stm32h7-series-stmicroelectronics.pdf
Application Notes | https://www.st.com/resource/en/application_note/an4891-stm32h72x-stm32h73x-and-singlecore-stm32h74x75x-system-architecture-and-performance-stmicroelectronics.pdf
Application Notes | https://www.st.com/resource/en/application_note/an4990-getting-started-with-sigmadelta-digital-interface-on-applicable-stm32-microcontrollers-stmicroelectronics.pdf
Application Notes | https://www.st.com/resource/en/application_note/an5027-interfacing-pdm-digital-microphones-using-stm32-mcus-and-mpus-stmicroelectronics.pdf
Application Notes | https://www.st.com/resource/en/application_note/an5033-stm32cube-mcu-package-examples-for-stm32h7-series-stmicroelectronics.pdf
Application Notes | https://www.st.com/resource/en/application_note/an5073-receiving-spdif-audio-stream-with-the-stm32f4f7h7-series-stmicroelectronics.pdf
Application Notes | https://www.st.com/resource/en/application_note/an5312-migration-from-revy-to-revv-for-stm32h743753-and-stm32h750-value-line-microcontrollers-stmicroelectronics.pdf

Application Notes | https://www.st.com/resource/en/application_note/an4899-stm32-microcontroller-gpio-hardware-settings-and-lowpower-consumption-stmicroelectronics.pdf
Application Notes | https://www.st.com/resource/en/application_note/an5612-esd-protection-of-stm32-mcus-and-mpus-stmicroelectronics.pdf
Application Notes | https://www.st.com/resource/en/application_note/an5293-migration-guide-from-stm32f7-series-to-stmh74x75x-stm32h72x73x-and-stmh7a37bx-devices-stmicroelectronics.pdf
Application Notes | https://www.st.com/resource/en/application_note/an4991-how-to-wake-up-an-stm32-microcontroller-from-lowpower-mode-with-the-usart-or-the-lpuart-stmicroelectronics.pdf
Application Notes | https://www.st.com/resource/en/application_note/an4838-introduction-to-memory-protection-unit-management-on-stm32-mcus-stmicroelectronics.pdf
Application Notes | https://www.st.com/resource/en/application_note/an4879-introduction-to-usb-hardware-and-pcb-guidelines-using-stm32-mcus-stmicroelectronics.pdf
Application Notes | https://www.st.com/resource/en/application_note/an5225-introduction-to-usb-typec-power-delivery-for-stm32-mcus-and-mpus-stmicroelectronics.pdf
Application Notes | https://www.st.com/resource/en/application_note/an5342--how-to-use-error-correction-code-ecc-management-for-internal-memories-protection-on-stm32-mcus-stmicroelectro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
Application Notes | https://www.st.com/resource/en/application_note/an4938-getting-started-with-stm32h74xig-and-stm32h75xig-mcu-hardware-development-stmicroelectronics.pdf
Application Notes | https://www.st.com/resource/en/application_note/an5537-how-to-use-adc-oversampling-techniques-to-improve-signaltonoise-ratio-on-stm32-mcus-stmicroelectronics.pdf
Application Notes | https://www.st.com/resource/en/application_note/an5405-how-to-use-fdcan-bootloader-protocol-on-stm32-mcus-stmicroelectronics.pdf
Application Notes | https://www.st.com/resource/en/application_note/an5690-how-to-use-vrefbuf-peripheral-on-stm32-mcus-and-mpus-stmicroelectronics.pdf
Application Notes | https://www.st.com/resource/en/application_note/an4230-introduction-to-

| random-number-generation-validation-using-the-nist-statistical-test-suite-for-stm32-mcus-and-mpus-stmicroelectronics.pdf
Application Notes | https://www.st.com/resource/en/application_note/an2867-guidelines-for-oscillator-design-on-stm8afals-and-stm32-mcusmpus-stmicroelectronics.pdf
Application Notes | https://www.st.com/resource/en/application_note/an4013-introduction-to-timers-for-stm32-mcus-stmicroelectronics.pdf
Application Notes | https://www.st.com/resource/en/application_note/an4277-how-to-use-pwm-shutdown-for-motor-control-and-digital-power-conversion-on-stm32-mcus-stmicroelectronics.pdf
Application Notes | https://www.st.com/resource/en/application_note/an4635-how-to-optimize-lpuart-power-consumption-on-stm32-mcus-stmicroelectronics.pdf
Application Notes | https://www.st.com/resource/en/application_note/an4861-introduction-to-lcdtft-display-controller-ltdc-on-stm32-mcus-stmicroelectronics.pdf
Application Notes | https://www.st.com/resource/en/application_note/an4908-getting-started-with-usart-automatic-baud-rater-detection-for-stm32-mcus-stmicroelectronics.pdf
Application Notes | https://www.st.com/resource/en/application_note/an4943-how-to-use-chromart-accelerator-to-refresh-an-lcdtft-display-on-stm32-mcus-stmicroelectronics.pdf
Application Notes | https://www.st.com/resource/en/application_note/an5156-introduction-to-security-for-stm32-mcus-stmicroelectronics.pdf
Application Notes | https://www.st.com/resource/en/application_note/an5224-introduction-to-dmamux-for-stm32-mcus-stmicroelectronics.pdf
Application Notes | https://www.st.com/resource/en/application_note/an5507-how-to-use-crc-to-check-the-integrity-of-the-internal-flash-memory-on-stm32h7-mcus-stmicroelectronics.pdf
Application Notes | https://www.st.com/resource/en/application_note/an5543-guidelines-for-enhanced-spi-communication-on-stm32-mcus-and-mpus-stmicroelectronics.pdf
Application Notes | https://www.st.com/resource/en/application_note/an5337-guidelines-for-estimating-stm32h7-mcus-lifetime-stmicroelectronics.pdf

Application Notes | https://www.st.com/resource/en/application_note/an4996-how-to-use-the-jpeg-codec-peripheral-on-stm32-mcus-stmicroelectronics.pdf
Application Notes | https://www.st.com/resource/en/application_note/an5348-introduction-to-fdcan-peripherals-for-stm32-mcus-stmicroelectronics.pdf
Application Notes | https://www.st.com/resource/en/application_note/cd00211314-how-to-optimize-the-adc-accuracy-in-the-stm32-mcus-stmicroelectronics.pdf
Application Notes | https://www.st.com/resource/en/application_note/an2639-soldering-recommendations-and-package-information-for-leadfree-ecopack2-mcus-and-mpus-stmicroelectronics.pdf
Application Notes | https://www.st.com/resource/en/application_note/an5020-introduction-to-digital-camera-interface-dcmi-for-stm32-mcus-stmicroelectronics.pdf
Application Notes | https://www.st.com/resource/en/application_note/an4566-how-to-extend-the-dac-performance-on-stm32-mcus-stmicroelectronics.pdf
Application Notes | https://www.st.com/resource/en/application_note/an5647-the-goertzel-algorithm-to-compute-individual-terms-of-the-discrete-fourier-transform-dft-in-stm32-products-stm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
Application Notes | https://www.st.com/resource/en/application_note/an2606-introduction-to-system-memory-boot-mode-on-stm32-mcus-stmicroelectronics.pdf
Application Notes | https://www.st.com/resource/en/application_note/an5200-getting-started-with-the-stm32h7-mcu-sdmmc-host-controller-stmicroelectronics.pdf
Application Notes | https://www.st.com/resource/en/application_note/an5036-guidelines-for-thermal-management-on-stm32-mcus-and-mpus-stmicroelectronics.pdf
Application Notes | https://www.st.com/resource/en/application_note/an3126-how-to-use-dac-for-audio-and-waveform-generation-on-stm32-mcus-and-mpus-stmicroelectronics.pdf
Application Notes | https://www.st.com/resource/en/application_note/an3155-how-to-use-usart-protocol-in-bootloader-on-stm32-mcus-stmicroelectronics.pdf
Application Notes | https://www.st.com/resource/en/application_note/an3156-how-to-use-usb-dfu-protocol-in-bootloader-on-stm32-mcus-stmicroelectronics.pdf
Application Notes | https://www.st.com/resource/en/application_note/an4286-how-to-use-spi-protocol-in-bootloader-on-stm32-mcus-stmicroelectronics.pdf
Application Notes | https://www.st.com/resource/en/application_note/an4759-introduction-to- using-the-hardware-realtime-clock-rtc-and-the-tamper-management-unit-

| tamp-for-stm32-mcus-stmicroelectronics.pdf
Application Notes | https://www.st.com/resource/en/application_note/an4760-introduction-to-quadspi-interface-for-stm32-mcus-and-mpus-stmicroelectronics.pdf
Application Notes | https://www.st.com/resource/en/application_note/an4776-how-to-use-generalpurpose-timer-peripheral-on-stm32-mcus-stmicroelectronics.pdf
Application Notes | https://www.st.com/resource/en/application_note/an4936-migrating-applications-from-stm32f7-to-stm32h743h753-mcus-stmicroelectronics.pdf
Application Notes | https://www.st.com/resource/en/application_note/an4989-introduction-to-debug-toolbox-for-stm32-mcus-stmicroelectronics.pdf
Application Notes | https://www.st.com/resource/en/application_note/an5927-how-to-use-i3c-protocol-in-bootloader-on-stm32-mcus-stmicroelectronics.pdf
Application Notes | https://www.st.com/resource/en/application_note/an5354-getting-started-with-16bit-adc-on-stm32h7-mcus-stmicroelectronics.pdf
Design Notes & Tips | https://www.st.com/resource/en/design_tip/dt0117-microphone-array-beamforming-in-the-pcm-and-pdm-domain-stmicroelectronics.pdf
Errata Sheets | https://www.st.com/resource/en/errata_sheet/es0392-stm32h742xig-stm32h743xig-stm32h750xb-stm32h753xi-device-errata-stmicroelectronics.pdf
Datasheet | https://www.st.com/resource/en/datasheet/dm00387108.pdf
Programming Manuals | https://www.st.com/resource/en/programming_manual/pm0253-stm32f7-series-and-stm32h7-series-cortexm7-processor-programming-manual-stmicroelectronics.pdf
Reference Manuals | https://www.st.com/resource/en/reference_manual/rm0433-stm32h742-stm32h743753-and-stm32h750-value-line-advanced-armbased-32bit-mcus-stmicroelectronics.pdf
Technical Notes & Articles | https://www.st.com/resource/en/technical_note/tn1163-description-of-wlcsp-for-microcontrollers-and-recommendations-for-its-use-stmicroelectronics.pdf
Technical Notes & Articles | https://www.st.com/resource/en/technical_note/tn1205-tape-and-reel-shipping-media-for-stm8-and-stm32-microcontrollers-in-fpn-packages-stmicroelectronics.pdf
Technical Notes | https://www.st.com/resource/en/technical_note/tn1206-tape-and-reel-

& Articles | shipping-media-for-stm8-and-stm32-microcontrollers-in-qfp-packages-stmicroelectronics.pdf
Technical Notes & Articles | https://www.st.com/resource/en/technical_note/tn1207-tape-and-reel-shipping-media-for-stm8-and-stm32-microcontrollers-in-so-packages-stmicroelectronics.pdf
Technical Notes & Articles | https://www.st.com/resource/en/technical_note/tn1208-tape-and-reel-shipping-media-for-stm8-and-stm32-microcontrollers-in-tssop-and-ssop-packages-stmicroelectronics.p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
Technical Notes & Articles | https://www.st.com/resource/en/technical_note/tn1433-reference-device-marking-schematics-for-stm32-microcontrollers-and-microprocessors-stmicroelectronics.pdf
Technical Notes & Articles | https://www.st.com/resource/en/technical_note/tn1204-tape-and-reel-shipping-media-for-stm32-devices-in-bga-packages-stmicroelectronics.pdf
User Manuals | https://www.st.com/resource/en/user_manual/um2840-stm32h7-dualcore-series-safety-manual-stmicroelectronics.pdf
User Manuals | https://www.st.com/resource/en/user_manual/um2331-stm32h7-singlecore-series-safety-manual-stmicroelectronics.pdf
User Manuals | https://www.st.com/resource/en/user_manual/um3252-stm32h7-series-ulcsaiec-607301603351-selftest-library-user-guide-stmicroelectronics.pdf

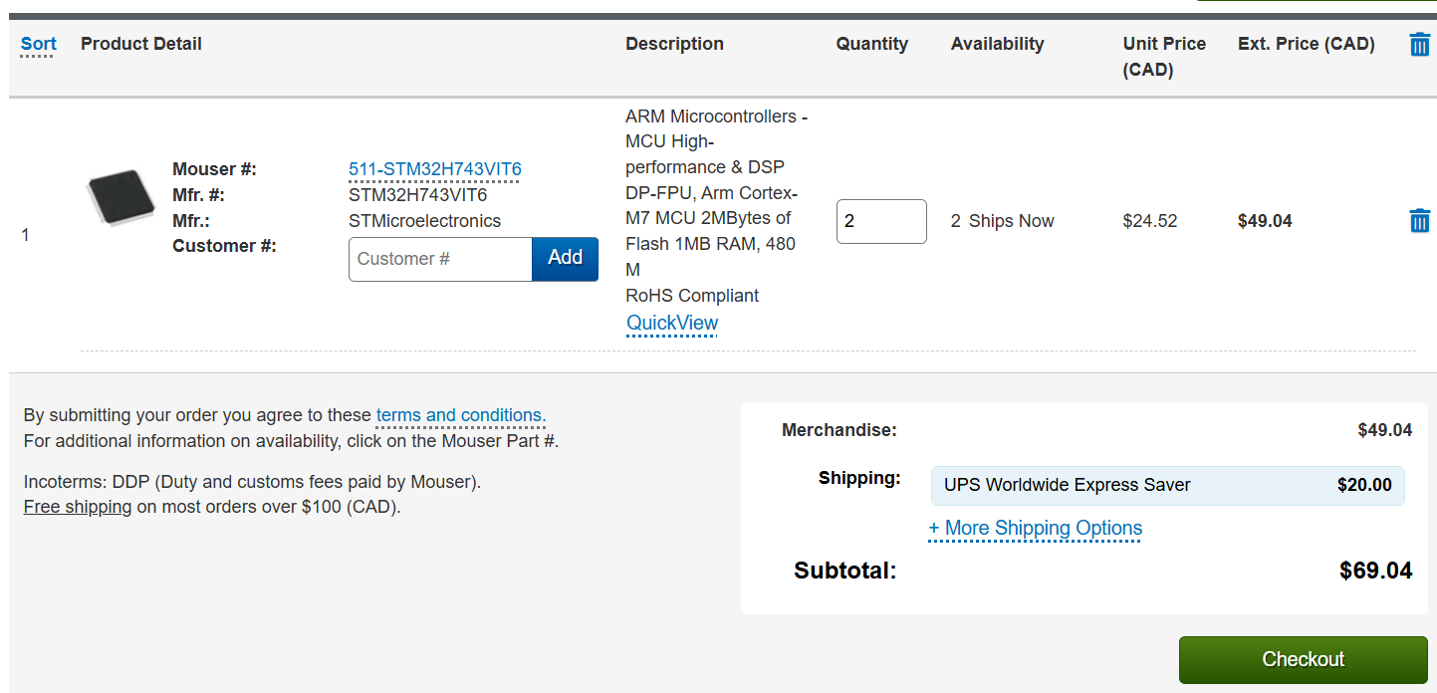
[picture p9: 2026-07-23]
hardware/Screenshots/Screenshot 2026-07-23 131647.png

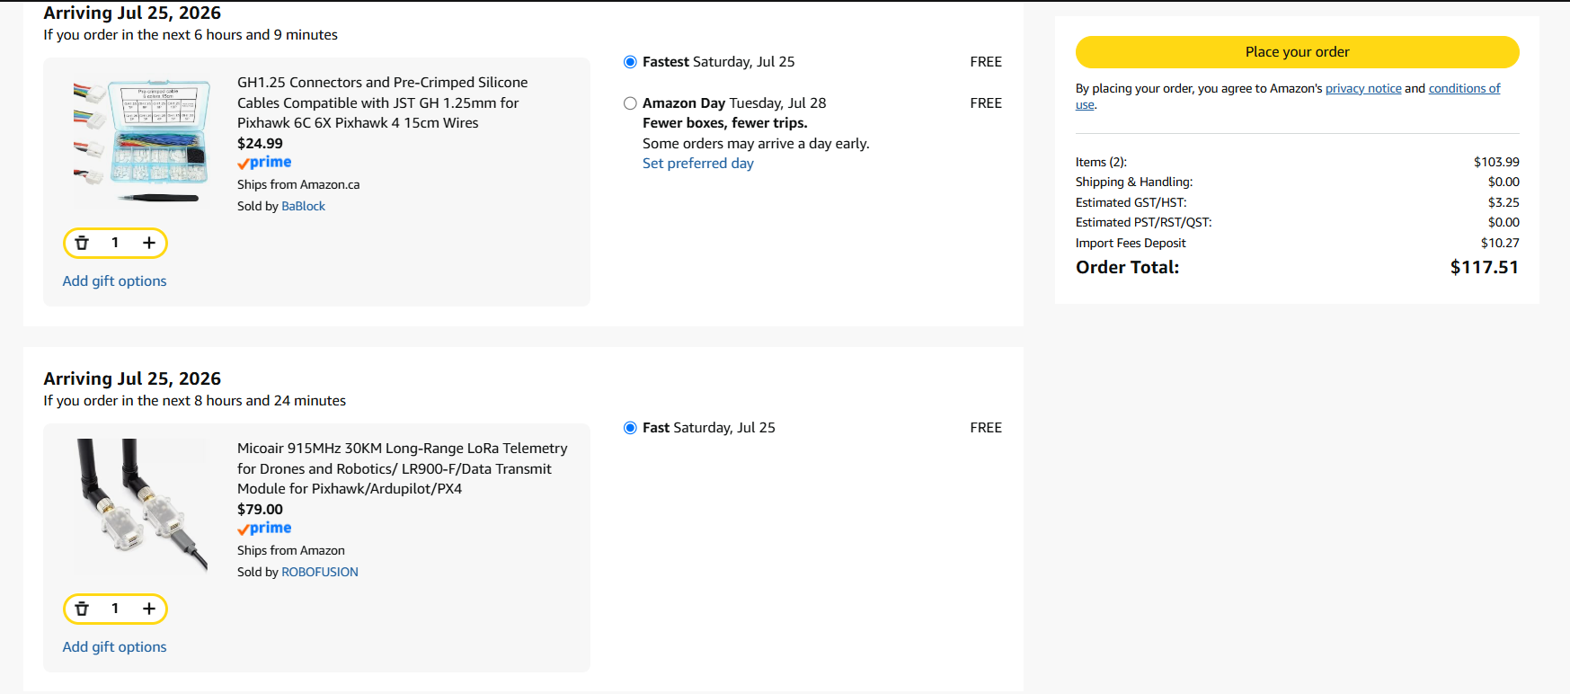
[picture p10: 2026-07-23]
hardware/Screenshots/Screenshot 2026-07-23 145006.png

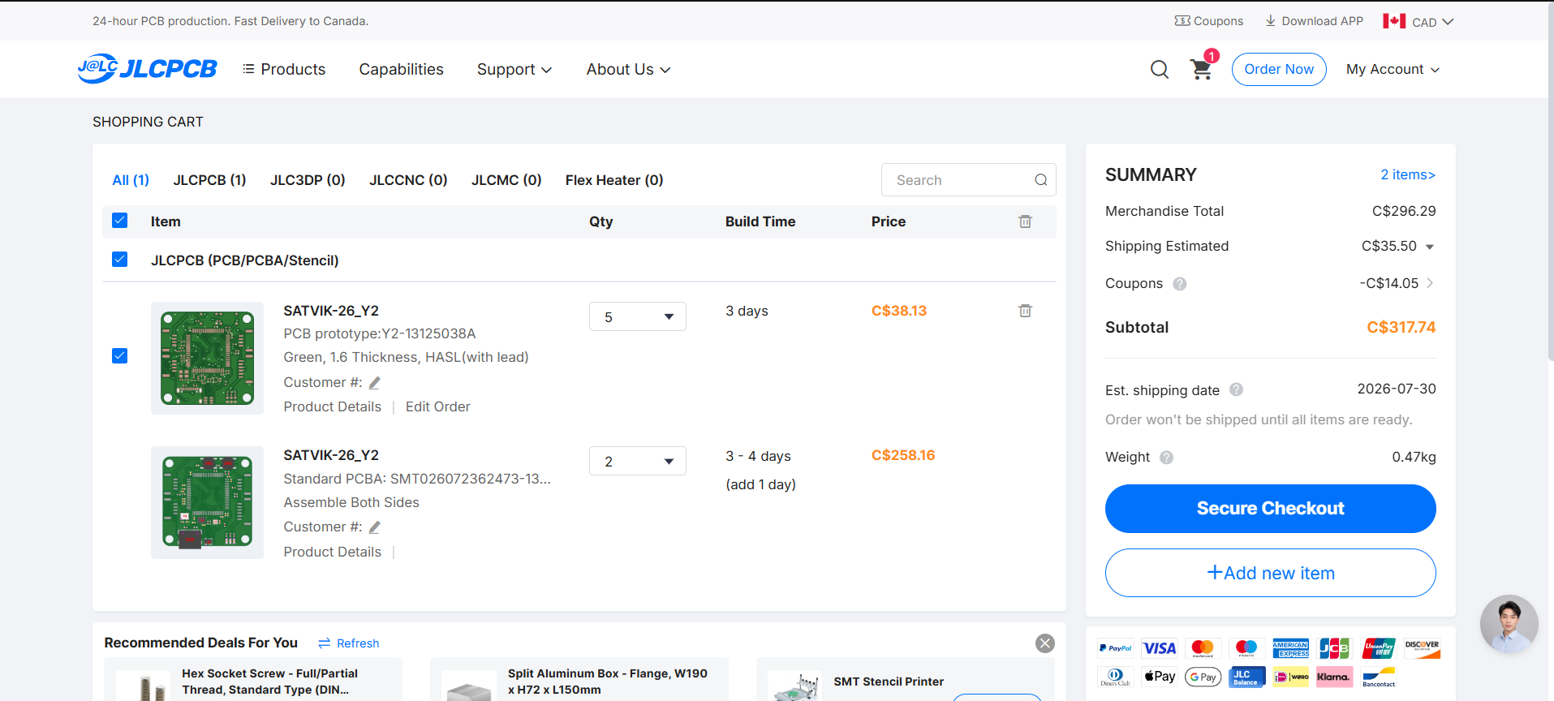
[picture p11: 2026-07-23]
hardware/Screenshots/Screenshot 2026-07-23 123427.png

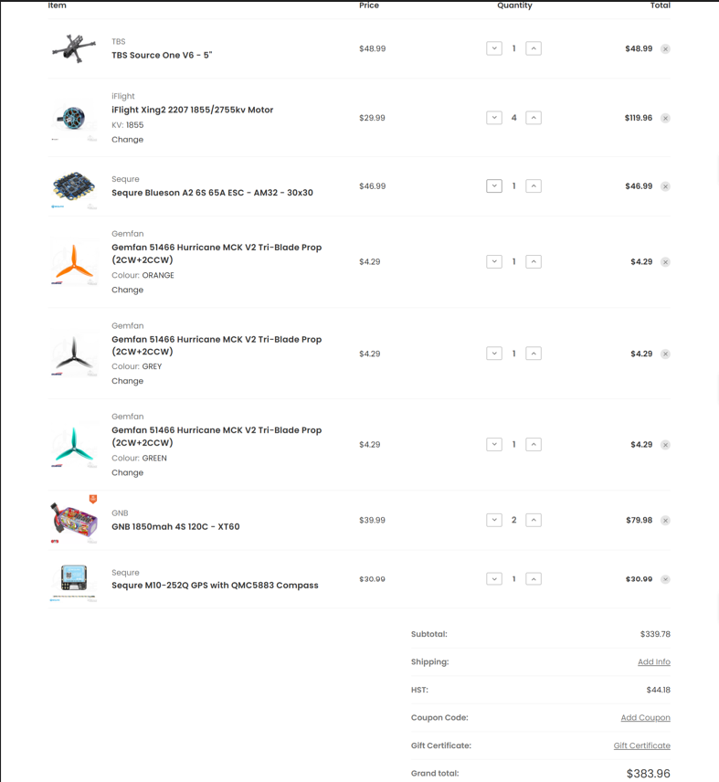
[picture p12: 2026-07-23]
hardware/Screenshots/Screenshot 2026-07-23 145532.png

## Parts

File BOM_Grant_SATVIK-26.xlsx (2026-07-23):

Category | Item | Recommended part | Qty | Unit C$ | Total | Supplier | Link | Notes
PCB & FC
 | JLCPCB PCBA order | Custom PCB with assembly from JLCPCB | 1 | 282.24 | 282.24 | JLCPCB | http://jlcpcb.com/
 | STM32H743VIT6 | Generic chip | 2 | 24.52 | 49.04 | Mouser | https://www.mouser.ca/en/ProductDetail/STMicroelectronics/STM32H743VIT6?qs=FNcb6ahWXRw0Me5k2ZHgWw%3D%3D | Out of stock at JLCPCB
 | JST-GH connector/cable set | Generic set | 1 | 24.99 | 24.99 | Amazon.ca | https://www.amazon.ca/gp/product/B07PBHN7TM/ref=ox_sc_act_title_1?smid=A1JTH8JAMM4IYJ&psc=1 | Out of stock at JLCPCB
AIRFRAME
 | 5in freestyle frame | TBS Source One V6 - 5" | 1 | 48.99 | 48.99 | Rotor Village | https://rotorvillage.ca/tbs-source-one-v6-5/
 | Motors 2207 ~1900KV | iFlight Xing2 2207 1855 | 4 | 29.99 | 119.96 | Rotor VIllage | https://rotorvillage.ca/iflight-xing2-2207-1855-2755kv-motor/
 | 4-in-1 ESC | Sequre Blueson A2 6S 65A ESC - AM32 | 1 | 46.99 | 46.99 | Rotor VIllage | https://rotorvillage.ca/sequre-blueson-a2-6s-65a-esc-am32/
 | Propellers 5in | Gemfan 51466 (4 set) | 3 | 4.29 | 12.87 | Rotor Village | https://rotorvillage.ca/gemfan-51466-hurricane-mck-v2-tri-blade-prop-2cw-2ccw/ | Some spares for testing
NAV & LINK
 | GPS + compass | Sequre M10-252Q GPS with QMC5883 | 1 | 30.99 | 30.99 | Rotor Village | https://rotorvillage.ca/sequre-m10-252q-gps-with-qmc5883-compass/
 | Telemetry radio pair | Micoair SiK Telemetry Radio, 915MHz | 1 | 79 | 79 | Amazon.ca | https://www.amazon.ca/gp/product/B0CP3X3KLG/ref=sw_img_1?smid=&psc=1
POWER
 | LiPo 4S 1500mAh | GNB 1850mah 4S 120C - XT60 | 2 | 39.99 | 79.98 | Rotor Village | https://rotorvillage.ca/gnb-1850mah-4s-120c-xt60/
SHIPPING AND TAX |  |  | Shipping | Tax
 | Mouser electronics | Shipping + Tax (Ontario HST) | 20 | 8.98 | 28.98
 | Amazon | Import fees + Tax | 10.27 | 3.25 | 13.52
 | Rotor Village | Shipping + Tax (Ontario HST) | 23.81 | 44.18 | 67.99
 | JLCPCB | Shipping | 35.5 | 0 | 35.5
 |  |  | TOTAL | CAD | C$921.04
 |  |  |  | USD | U$654.11
REGULATORY | Just for awarness and safety, personal cost, not included in the total
 | TC Small Basic Exam | Online exam | 1 | 10 | 10 | Transport Canada
 | Drone registration | Per aircraft | 1 | 5 | 5 | Transport Canada

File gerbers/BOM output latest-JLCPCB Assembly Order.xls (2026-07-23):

JLCPCB BOM Tool - BOM Matching
BOM name：BOM output latest-JLCPCB Assembly Order.xlsx |  |  | Download Time：2026-07-24 04:09:19 |  |  |  | * Our matching results are updated in real-time, but stock and prices may change. If it's been over 24 hours, please re-match before placing your order.
PCB Assembled Qty：5 |  |  | Est. Total Price：59.5537
Your BOM |  |  |  |  | Matched Parts |  |  |  |  |  |  | Order Information
Top Designator | Bottom Designator | Comment | Footprint | JLCPCB Part # | Matches | Part # | Manufacturer | Footprint | Description | Category | Warning | JLCPCB Part # | Product link | Lib Type | Qty | Source | Total Price ($)
C1,C2 |  | 2.2uF | 0402 |  | Select by System | CL05A225MQ5NSNC | Samsung Electro-Mechanics | 0402 | 2.2uF 6.3V X5R ±20% 0402 Multilayer Ceramic Capacitors MLCC - SMD/SMT ROHS | Multilayer Ceramic Capacitors MLCC - SMD/SMT |  | C12530 | https://jlcpcb.com/partdetail/13164-CL05A225MQ5NSNC/C12530 | Basic | 20 | 20 JLCPCB | 0.212
C3,C8,C9,C10,C11,C12,C13,C23,C24,C25,C26,C27,C28,C29 | C16 | 100nF | 0402 |  | Select by System | CL05B104KO5NNNC | Samsung Electro-Mechanics | 0402 | 100nF 16V X7R ±10% 0402 Multilayer Ceramic Capacitors MLCC - SMD/SMT ROHS | Multilayer Ceramic Capacitors MLCC - SMD/SMT |  | C1525 | https://jlcpcb.com/partdetail/1877-CL05B104KO5NNNC/C1525 | Basic | 58 | 58 JLCPCB | 0.3074
C4,C5 |  | 15pF | 0402 |  | Select by System | 0402CG150J500NT | FH (Guangdong Fenghua Advanced Tech) | 0402 | 15pF 50V C0G ±5% 0402 Multilayer Ceramic Capacitors MLCC - SMD/SMT ROHS | Multilayer Ceramic Capacitors MLCC - SMD/SMT |  | C1548 | https://jlcpcb.com/partdetail/1900-0402CG150J500NT/C1548 | Basic | 20 | 20 JLCPCB | 0.102
 | C6,C7 | 10uF | 1206 |  | Select by System | CL31A106KBHNNNE | Samsung Electro-Mechanics | 1206 | 10uF 50V X5R ±10% 1206 Multilayer Ceramic Capacitors MLCC - SMD/SMT ROHS | Multilayer Ceramic Capacitors MLCC - SMD/SMT |  | C13585 | https://jlcpcb.com/partdetail/14236-CL31A106KBHNNNE/C13585 | Basic | 8 | 8 JLCPCB | 3.62
 | C14,C15 | 4.7uF | 0603 |  | Select by System | CL10A475KO8NNNC | Samsung Electro-Mechanics | 0603 | 16V 4.7uF X5R ±10% 0603 Multilayer Ceramic Capacitors MLCC - SMD/SMT ROHS | Multilayer Ceramic Capacitors MLCC - SMD/SMT |  | C19666 | https://jlcpcb.com/partdetail/20375-CL10A475KO8NNNC/C19666 | Basic | 20 | 20 JLCPCB | 0.738
 | C17,C18 | 47uF | 1206 |  | Select by System | CL31A476MPHNNNE | Samsung Electro-Mechanics | 1206 | 10V 47uF X5R ±20% 1206 Multilayer Ceramic Capacitors MLCC - SMD/SMT ROHS | Multilayer Ceramic Capacitors MLCC - SMD/SMT |  | C96123 | https://jlcpcb.com/partdetail/97327-CL31A476MPHNNNE/C96123 | Basic | 8 | 8 JLCPCB | 3.0824
 | C19 | 3.3nF | 0402 |  | Select by System | CL05B332KB5NNNC | Samsung Electro-Mechanics | 0402 | 3.3nF 50V X7R ±10% 0402 Multilayer Ceramic Capacitors MLCC - SMD/SMT ROHS | Multilayer Ceramic Capacitors MLCC - SMD/SMT |  | C26404 | https://jlcpcb.com/partdetail/27148-CL05B332KB5NNNC/C26404 | Extended | 20 | 20 JLCPCB | 0.156
 | C20 | 100pF | 0402 |  | Select by System | 0402CG101J500NT | FH (Guangdong Fenghua Advanced Tech) | 0402 | 100pF 50V C0G ±5% 0402 Multilayer Ceramic Capacitors MLCC - SMD/SMT ROHS | Multilayer Ceramic Capacitors MLCC - SMD/SMT |  | C1546 | https://jlcpcb.com/partdetail/1898-0402CG101J500NT/C1546 | Basic | 20 | 20 JLCPCB | 0.192
C22 | C21,C30 | 1uF | 0402 |  | Select by System | CL05A105KA5NQNC | Samsung Electro-Mechanics | 0402 | 1uF 25V X5R ±10% 0402 Multilayer Ceramic Capacitors MLCC - SMD/SMT ROHS | Multilayer Ceramic Capacitors MLCC - SMD/SMT |  | C52923 | https://jlcpcb.com/partdetail/53938-CL05A105KA5NQNC/C52923 | Basic | 40 | 40 JLCPCB | 1.06
 | D1 | SS56 | SMA |  | Select by System | SS56 | MDD(Microdiode Semiconductor) | SMA(DO-214AC) | -55℃~+150℃ 1mA@60V 5A 60V 700mV@5A Independent SMA(DO-214AC) Schottky Diodes ROHS | Schottky Diodes |  | C65009 | https://jlcpcb.com/partdetail/MDD_Microdiode_Semiconductor-SS56/C65009 | Extended | 6 | 6 JLCPCB | 0.3126
 | D2 | SMBJ26A | SMB |  | Select by System | SMBJ26A | Slkor(SLKORMICRO Elec.) | SMB(DO-214AA) | -55℃~+150℃ 14.3A 26V 33.2V 42.1V 5uA 600W TVS Unidirectional SMB(DO-214AA) ESD and Surge Protection (TVS/ESD) ROHS | ESD And Surge Protection (TVS/ESD) |  | C3019963 | https://jlcpcb.com/partdetail/Slkor_SLKORMICRO_Elec-SMBJ26A/C3019963 | Extended | 5 | 5 JLCPCB | 0.2185
D3,D4,D5 |  | LEDwhite | 0603 |  | Select by System | KT-0603W | Hubei KENTO Elec | 0603 | -40℃~+85℃ 100mW 120° 2.6V~3.1V 360mcd 5mA Discrete Diode Top-mount White Yellow Lens 0603 LED Indication - Discrete ROHS | LED Indication - Discrete |  | C2290 | https://jlcpcb.com/partdetail/Hubei_KENTOElec-KT0603W/C2290 | Basic | 20 | 20 JLCPCB | 0.242
 | J1 | DM3AT-SF-PEJM5 | microSD_HC_Hirose_DM3AT-SF-PEJM5 |  | Select by System | DM3AT-SF-PEJM5 | HRS(Hirose) | SMD | -25℃~+85℃ 1.68mm Connector and Ejector MicroSD Card (TF Card) No Push-Push SMD SD Card / Memory Card Connector ROHS | SD Card / Memory Card Connector |  | C114218 | https://jlcpcb.com/partdetail/HRS_Hirose-DM3AT_SFPEJM5/C114218 | Extended | 2 | 2 JLCPCB | 3.4258
 | J4 | SM03B-GHS-TB | JST_GH_SM03B-GHS-TB_1x03-1MP_P1.25mm_Horizontal |  | Select by System | SM03B-GHS-TB(LF)(SN) | JST | SMD,P=1.25mm,卧贴 | -25℃~+85℃ 1 1.25mm 1A 1x3P 3 3P 4.13mm 4.25mm 50V 7mm Auxiliary Solder Pin GH PA9T Phosphor bronze Surface Mount, Right Angle Tin UL94V-0 White SMD,P=1.25mm,卧贴 Wire To Board Connector ROHS | Wire To Board Connector |  | C514175 | https://jlcpcb.com/partdetail/JST-SM03B_GHS_TB_LF_SN/C514175 | Extended | 5 | 5 JLCPCB | 1.394
 | L1 | 15uH | SMD,10.4x10.3mm |  | Select by System | SMDRH104R-150MT | SXN(Shun Xiang Nuo Elec) | SMD,10.4x10.3mm | 15uH 3.1A 4.4A 50mΩ Magnetic Shielded Inductor ±20% SMD,10.4x10.3mm Power Inductors ROHS | Power Inductors |  | C16113 | https://jlcpcb.com/partdetail/16795-SMDRH104R150MT/C16113 | Extended | 2 | 2 JLCPCB | 0.3748
R1,R8 | R6 | 10k | 0402 |  | Select by System | 0402WGF1002TCE | UNI-ROYAL(Uniroyal Elec) | 0402 | -55℃~+155℃ 10kΩ 50V 62.5mW Thick Film Resistor ±1% ±100ppm/℃ 0402 Chip Resistor - Surface Mount ROHS | Chip Resistor - Surface Mount |  | C25744 | https://jlcpcb.com/partdetail/26487-0402WGF1002TCE/C25744 | Basic | 40 | 40 JLCPCB | 0.08
 | R2,R4 | 100k | 0402 |  | Select by System | 0402WGF1003TCE | UNI-ROYAL(Uniroyal Elec) | 0402 | -55℃~+155℃ 100kΩ 50V 62.5mW Thick Film Resistor ±1% ±100ppm/℃ 0402 Chip Resistor - Surface Mount ROHS | Chip Resistor - Surface Mount |  | C25741 | https://jlcpcb.com/partdetail/26484-0402WGF1003TCE/C25741 | Basic | 20 | 20 JLCPCB | 0.032
 | R3 | 24.9k | 0402 |  | Select by Customer | RC0402FR-0724K9L | YAGEO | 0402 | -55℃~+155℃ 24.9kΩ 50V 62.5mW Thick Film Resistor ±1% ±100ppm/℃ 0402 Chip Resistor - Surface Mount ROHS | Chip Resistor - Surface Mount |  | C138027 | https://jlcpcb.com/partdetail/YAGEO-RC0402FR0724K9L/C138027 | Extended | 20 | 20 JLCPCB | 0.11
 | R5 | 52.3k | 0402 |  | Select by System | 0402WGF5232TCE | UNI-ROYAL(Uniroyal Elec) | 0402 | -55℃~+155℃ 50V 52.3kΩ 62.5mW Thick Film Resistor ±1% ±100ppm/℃ 0402 Chip Resistor - Surface Mount ROHS | Chip Resistor - Surface Mount |  | C26982 | https://jlcpcb.com/partdetail/27731-0402WGF5232TCE/C26982 | Extended | 20 | 20 JLCPCB | 0.032
 | R7 | 4.99k | 0402 |  | Select by Customer | RC0402FR-074K99L | YAGEO | 0402 | -55℃~+155℃ 4.99kΩ 50V 62.5mW Thick Film Resistor ±1% ±100ppm/℃ 0402 Chip Resistor - Surface Mount ROHS | Chip Resistor - Surface Mount |  | C137965 | https://jlcpcb.com/partdetail/YAGEO-RC0402FR074K99L/C137965 | Extended | 20 | 20 JLCPCB | 0.108
R9,R20,R21 |  | 1k | 0402 |  | Select by System | 0402WGF1001TCE | UNI-ROYAL(Uniroyal Elec) | 0402 | -55℃~+155℃ 1kΩ 50V 62.5mW Thick Film Resistor ±1% ±100ppm/℃ 0402 Chip Resistor - Surface Mount ROHS | Chip Resistor - Surface Mount |  | C11702 | https://jlcpcb.com/partdetail/12256-0402WGF1001TCE/C11702 | Basic | 20 | 20 JLCPCB | 0.034
R10,R11 |  | 4.7k | 0402 |  | Select by System | 0402WGF4701TCE | UNI-ROYAL(Uniroyal Elec) | 0402 | -55℃~+155℃ 4.7kΩ 50V 62.5mW Thick Film Resistor ±1% ±100ppm/℃ 0402 Chip Resistor - Surface Mount ROHS | Chip Resistor - Surface Mount |  | C25900 | https://jlcpcb.com/partdetail/26643-0402WGF4701TCE/C25900 | Basic | 20 | 20 JLCPCB | 0.034
R12,R13 |  | 5.1k | 0402 |  | Select by System | 0402WGF5101TCE | UNI-ROYAL(Uniroyal Elec) | 0402 | -55℃~+155℃ 5.1kΩ 50V 62.5mW Thick Film Resistor ±1% ±100ppm/℃ 0402 Chip Resistor - Surface Mount ROHS | Chip Resistor - Surface Mount |  | C25905 | https://jlcpcb.com/partdetail/26648-0402WGF5101TCE/C25905 | Basic | 20 | 20 JLCPCB | 0.028
R14,R15,R16,R17,R18,R19 |  | 47k | 0402 |  | Select by System | 0402WGF4702TCE | UNI-ROYAL(Uniroyal Elec) | 0402 | -55℃~+155℃ 47kΩ 50V 62.5mW Thick Film Resistor ±1% ±100ppm/℃ 0402 Chip Resistor - Surface Mount ROHS | Chip Resistor - Surface Mount |  | C25792 | https://jlcpcb.com/partdetail/26535-0402WGF4702TCE/C25792 | Basic | 22 | 22 JLCPCB | 0.143
R22,R23 |  | 330 | 0402 |  | Select by System | 0402WGF3300TCE | UNI-ROYAL(Uniroyal Elec) | 0402 | -55℃~+155℃ 330Ω 50V 62.5mW Thick Film Resistor ±1% ±100ppm/℃ 0402 Chip Resistor - Surface Mount ROHS | Chip Resistor - Surface Mount |  | C25104 | https://jlcpcb.com/partdetail/25847-0402WGF3300TCE/C25104 | Basic | 20 | 20 JLCPCB | 0.034
SW1,SW2 |  | TS-1187A-B-A-B | SW-SMD_4P-L5.1-W5.1-P3.70-LS6.5-TL_H1.5 |  | Select by System | TS-1187A-B-A-B | XKB Connection | SMD-4P,5.1x5.1mm | -30℃~+85℃ 1.5mm 1.6N 100,000 cycles 12V 5.1mm 5.1mm 50mA Gold No Round Button SPST Surface Mount,Vertical Without Bracket SMD-4P,5.1x5.1mm Tactile Switches ROHS | Tactile Switches |  | C318884 | https://jlcpcb.com/partdetail/XKBConnection-TS_1187A_B_AB/C318884 | Basic | 9 | 9 JLCPCB | 0.1836
 | U2 | TPS54560BDDA | SOIC-8-EP |  | Select by System | TPS54560DDAR | Texas Instruments | SOIC-8-EP | -40℃~+150℃@(TJ) 1 146uA 2.5MHz 4.5V~60V 5A 800mV~58.8V Adjustable Buck Buck Built-in No SOIC-8-EP DC-DC Converters ROHS | DC-DC Converters |  | C31966 | https://jlcpcb.com/partdetail/TexasInstruments-TPS54560DDAR/C31966 | Extended | 2 | 2 JLCPCB | 2.1914
 | U3 | AP2112K-3.3 | SOT-23-5 |  | Select by System | AP2112K-3.3TRG1 | Diodes Incorporated | SOT-25-5 | -40℃~+85℃@(Ta) 1 250mV@(600mA) 3.3V 50uVrms 55uA 600mA 65dB@(1kHz) 6V Fixed Over Current Protection、Thermal Shutdown、Enable control Positive SOT-25-5 Voltage Regulators - Linear, Low Drop Out (LDO) Regulators ROHS | Voltage Regulators - Linear, Low Drop Out (LDO) Regulators |  | C51118 | https://jlcpcb.com/partdetail/DiodesIncorporated-AP2112K_33TRG1/C51118 | Extended | 5 | 5 JLCPCB | 0.836
U4 |  | ICM-42688-P | LGA-14 |  | Select by System | ICM-42688-P | TDK InvenSense | LGA-14(2.5x3) | -40℃~+85℃ 1.71V~3.6V 16bit 2KB 7.5uA IMU (accelerometer + gyroscope) SPI、I2C X,Y,Z X,Y,Z ±16g ±2000dps Motion Event Detection, Synchronization, Timestamp Support LGA-14(2.5x3) Accelerometers ROHS | Accelerometers |  | C1850418 | https://jlcpcb.com/partdetail/TDKInvenSense-ICM_42688P/C1850418 | Extended | 2 | 2 JLCPCB | 33.686
U5 |  | BMP388 | LGA-10 |  | Select by System | BMP388 | Bosch Sensortec | LGA-10(2x2) | -40℃~+85℃ 1.65V~3.6V 1pa/K 2uA 30Kpa~1.25bar 50pa 8pa I2C、SPI LGA-10(2x2) Pressure Sensors ROHS | Pressure Sensors |  | C779278 | https://jlcpcb.com/partdetail/BoschSensortec-BMP388/C779278 | Extended | 2 | 2 JLCPCB | 5.124
U6 |  | USBLC6-2SC6 | SOT-23-6 |  | Select by System | USBLC6-2SC6 | TECH PUBLIC | SOT-23-6 | -55℃~+125℃ 0.35pF 12V 150W 2 5V 6A 6V 80nA ESD IEC 61000-4-2、IEC 61000-4-5、IEC 61000-4-4 Unidirectional SOT-23-6 ESD and Surge Protection (TVS/ESD) ROHS | ESD And Surge Protection (TVS/ESD) |  | C2827654 | https://jlcpcb.com/partdetail/TECHPUBLIC-USBLC62SC6/C2827654 | Extended | 6 | 6 JLCPCB | 0.2652
USB1 |  | TYPE-C16PIN2MD | USB-C-SMD_TYPE-C-16PIN-2MD-073 |  | Select by System | TYPE-C 16PIN 2MD(073) | SHOU HAN | SMD | -25℃~+85℃ 1 16P 3A 5,000 times 5V Black Female Surface Mount, Right Angle Type-C SMD USB Connectors ROHS | USB Connectors |  | C2765186 | https://jlcpcb.com/partdetail/SHOUHAN-TYPE_C_16PIN_2MD_073/C2765186 | Extended | 3 | 3 JLCPCB | 0.2205
Y1 |  | 8MHz | SMD3225-4P |  | Select by System | X32258MOB4SI | YXC Crystal Oscillators | SMD3225-4P | -40℃~+85℃ 12pF 150Ω 8MHz Crystal Oscillator ±10ppm ±20ppm SMD3225-4P Crystals ROHS | Crystals |  | C2682775 | https://jlcpcb.com/partdetail/2777872-X32258MOB4SI/C2682775 | Extended | 5 | 5 JLCPCB | 0.9745
 | J2 | SM08B-GHS-TB | JST_GH_SM08B-GHS-TB_1x08-1MP_P1.25mm_Horizontal |  | Select by System | SM08B-GHS-TB | JST | SMD-8P | SMD-8P New Arrivals ROHS | Global Sourcing Parts |  | C22391766 | https://jlcpcb.com/partdetail/JST-SM08B_GHSTB/C22391766 | Extended | 2 | 0 JLCPCB | 0
J3 |  | SM06B-GHS-TB | JST_GH_SM06B-GHS-TB_1x06-1MP_P1.25mm_Horizontal |  | Select by System | SM06B-GHS-TB | JST | SMD,P=1.25mm,卧贴 | -25℃~+85℃ 1 1.25mm 10.75mm 1A 1x6P 4.13mm 4.25mm 50V 6 6P Auxiliary Solder Pin GH PA9T Phosphor bronze Surface Mount, Right Angle Tin UL94V-0 White SMD,P=1.25mm,卧贴 Wire To Board Connector ROHS | Global Sourcing Parts |  | C19626244 | https://jlcpcb.com/partdetail/JST-SM06B_GHSTB/C19626244 | Extended | 2 | 0 JLCPCB | 0
J5,J6,J7 |  | SM04B-GHS-TB | JST_GH_SM04B-GHS-TB_1x04-1MP_P1.25mm_Horizontal |  | Select by System | SM04B-GHS-TB | JST | SMD,P=1.25mm,卧贴 | -25℃~+85℃ 1 1.25mm 1A 1x4P 4 4.13mm 4.25mm 4P 50V 8.25mm Auxiliary Solder Pin GH PA9T Phosphor bronze Surface Mount, Right Angle Tin UL94V-0 White SMD,P=1.25mm,卧贴 Wire To Board Connector ROHS | Global Sourcing Parts |  | C20584968 | https://jlcpcb.com/partdetail/JST-SM04B_GHSTB/C20584968 | Extended | 6 | 0 JLCPCB | 0
U1 |  | STM32H743VIT6 | LQFP-100 |  | Select by System | STM32H743VIT6 | STMicroelectronics | LQFP-100(14x14) | -40℃~+85℃ 1.71V~3.6V 12bit 16bit 1MB 2MB 32 Bit 480MHz 82 ARM Cortex-M7 Built-in FLASH LQFP-100(14x14) Microcontrollers (MCU/MPU/SOC) ROHS | Microcontrollers (MCU/MPU/SOC) |  | C114409 | https://jlcpcb.com/partdetail/STMicroelectronics-STM32H743VIT6/C114409 | Extended | 2 | 0 JLCPCB | 0

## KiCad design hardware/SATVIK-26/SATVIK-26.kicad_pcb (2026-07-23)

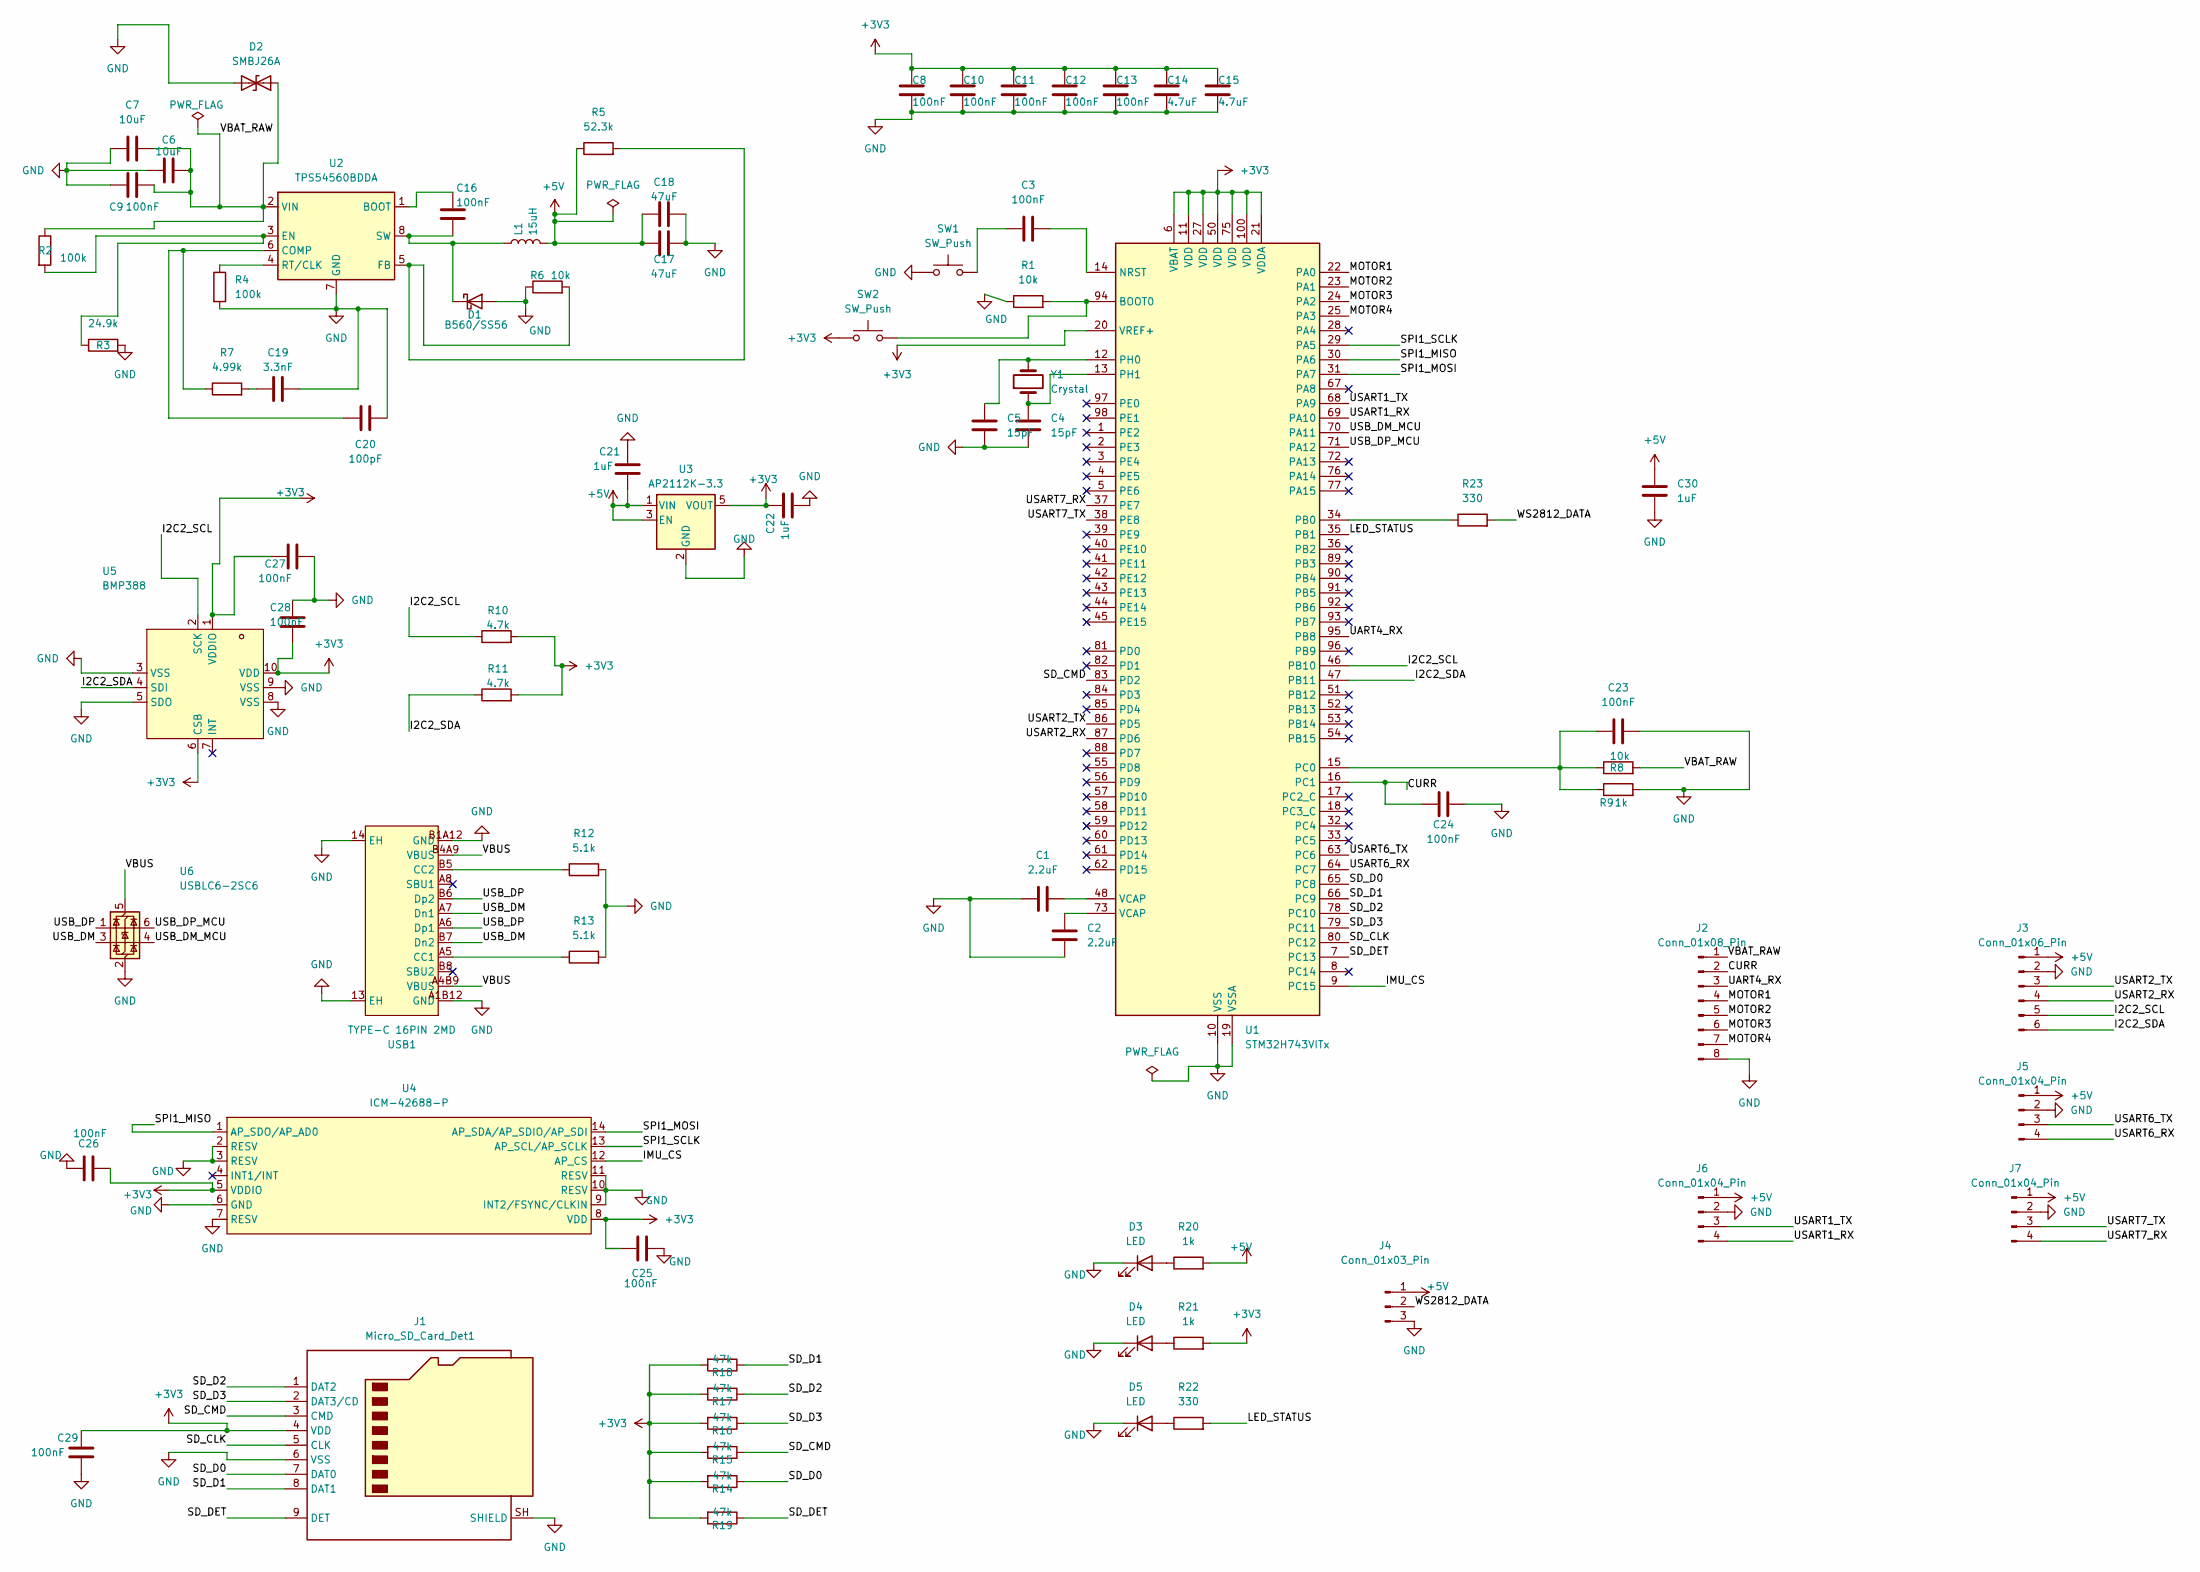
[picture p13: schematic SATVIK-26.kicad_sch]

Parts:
C1, C2: 2.2uF; C_0402_1005Metric
C3, C8, C9, C10, C11, C12, C13, C16, C23, C24, C25, C26, C27, C28, C29: 100nF; C_0402_1005Metric
C4, C5: 15pF; C_0402_1005Metric
C6, C7: 10uF; C_1206_3216Metric
C14, C15: 4.7uF; C_0603_1608Metric
C17, C18: 47uF; C_1206_3216Metric
C19: 3.3nF; C_0402_1005Metric
C20: 100pF; C_0402_1005Metric
C21, C22, C30: 1uF; C_0402_1005Metric
D1: B560/SS56; D_SMA
D2: SMBJ26A; D_SMB
D3, D4, D5: LED; LED_0603_1608Metric
J1: Micro_SD_Card_Det1; microSD_HC_Hirose_DM3AT-SF-PEJM5
J2: Conn_01x08_Pin; JST_GH_SM08B-GHS-TB_1x08-1MP_P1.25mm_Horizontal
J3: Conn_01x06_Pin; JST_GH_SM06B-GHS-TB_1x06-1MP_P1.25mm_Horizontal
J4: Conn_01x03_Pin; JST_GH_SM03B-GHS-TB_1x03-1MP_P1.25mm_Horizontal
J5, J6, J7: Conn_01x04_Pin; JST_GH_SM04B-GHS-TB_1x04-1MP_P1.25mm_Horizontal
L1: 15uH; IND-SMD_L10.4-W10.3
R1, R6, R8: 10k; R_0402_1005Metric
R2, R4: 100k; R_0402_1005Metric
R3: 24.9k; R_0402_1005Metric
R5: 52.3k; R_0402_1005Metric
R7: 4.99k; R_0402_1005Metric
R9, R20, R21: 1k; R_0402_1005Metric
R10, R11: 4.7k; R_0402_1005Metric
R12, R13: 5.1k; R_0402_1005Metric
R14, R15, R16, R17, R18, R19: 47k; R_0402_1005Metric
R22, R23: 330; R_0402_1005Metric
SW1, SW2: SW_Push; SW-SMD_4P-L5.1-W5.1-P3.70-LS6.5-TL_H1.5
U1: STM32H743VITx; LQFP-100_14x14mm_P0.5mm
U2: TPS54560BDDA; Texas_R-PDSO-G8_EP2.95x4.9mm_Mask2.4x3.1mm_ThermalVias
U3: AP2112K-3.3; SOT-23-5
U4: ICM-42688-P; LGA-14_L3.0-W2.5-P0.50-TL; MPN ICM-42688-P; LCSC Part C1850418
U5: BMP388; SENSORM-SMD_BMP388; MPN BMP388; LCSC Part C779278
U6: USBLC6-2SC6; SOT-23-6
USB1: TYPE-C 16PIN 2MD; USB-C-SMD_TYPE-C-16PIN-2MD-073; MPN TYPE-C 16PIN 2MD(073); LCSC Part C2765186
Y1: Crystal; CRYSTAL-SMD_4P-L3.2-W2.5-BL

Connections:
+3V3: C8.1, C10.1, C11.1, C12.1, C13.1, C14.1, C15.1, C22.1, C25.1, C26.1, C27.1, C28.2, C29.1, J1.4 (VDD), R10.2, R11.2, R14.2, R15.2, R16.2, R17.2, R18.2, R19.2, R21.2, SW2.1, U1.6 (VBAT), U1.11 (VDD), U1.20 (VREF+), U1.21 (VDDA), U1.27 (VDD), U1.50 (VDD), U1.75 (VDD), U1.100 (VDD), U3.5 (VOUT), U4.5 (VDDIO), U4.8 (VDD), U5.1 (VDDIO), U5.6 (CSB), U5.10 (VDD)
+5V: C17.1, C18.1, C21.2, C30.1, J3.1, J4.1, J5.1, J6.1, J7.1, L1.2, R5.1, R20.2, U3.1 (VIN), U3.3 (EN)
/CURR: C24.2, J2.2, U1.16 (PC1)
/I2C2_SCL: J3.5, R10.1, U1.46 (PB10), U5.2 (SCK)
/I2C2_SDA: J3.6, R11.1, U1.47 (PB11), U5.4 (SDI)
/IMU_CS: U1.9 (PC15), U4.12 (AP_CS)
/LED_STATUS: R22.2, U1.35 (PB1)
/MOTOR1: J2.4, U1.22 (PA0)
/MOTOR2: J2.5, U1.23 (PA1)
/MOTOR3: J2.6, U1.24 (PA2)
/MOTOR4: J2.7, U1.25 (PA3)
/SD_CLK: J1.5 (CLK), U1.80 (PC12)
/SD_CMD: J1.3 (CMD), R15.1, U1.83 (PD2)
/SD_D0: J1.7 (DAT0), R14.1, U1.65 (PC8)
/SD_D1: J1.8 (DAT1), R18.1, U1.66 (PC9)
/SD_D2: J1.1 (DAT2), R17.1, U1.78 (PC10)
/SD_D3: J1.2 (DAT3/CD), R16.1, U1.79 (PC11)
/SD_DET: J1.9 (DET), R19.1, U1.7 (PC13)
/SPI1_MISO: U1.30 (PA6), U4.1 (AP_SDO/AP_AD0)
/SPI1_MOSI: U1.31 (PA7), U4.14 (AP_SDA/AP_SDIO/AP_SDI)
/SPI1_SCLK: U1.29 (PA5), U4.13 (AP_SCL/AP_SCLK)
/UART4_RX: J2.3, U1.95 (PB8)
/USART1_RX: J6.4, U1.69 (PA10)
/USART1_TX: J6.3, U1.68 (PA9)
/USART2_RX: J3.4, U1.87 (PD6)
/USART2_TX: J3.3, U1.86 (PD5)
/USART6_RX: J5.4, U1.64 (PC7)
/USART6_TX: J5.3, U1.63 (PC6)
/USART7_RX: J7.4, U1.37 (PE7)
/USART7_TX: J7.3, U1.38 (PE8)
/USB_DM: U6.3 (I/O2), USB1.A7 (Dn1), USB1.B7 (Dn2)
/USB_DM_MCU: U1.70 (PA11), U6.4 (I/O2)
/USB_DP: U6.1 (I/O1), USB1.A6 (Dp1), USB1.B6 (Dp2)
/USB_DP_MCU: U1.71 (PA12), U6.6 (I/O1)
/VBAT_RAW: C6.2, C7.2, C9.2, D2.1 (A1), J2.1, R2.1, R8.2, U2.2 (VIN)
/VBUS: U6.5 (VBUS), USB1.A4B9 (VBUS), USB1.B4A9 (VBUS)
/WS2812_DATA: J4.2, R23.2
GND: C1.1, C2.2, C4.1, C5.1, C6.1, C7.1, C8.2, C9.1, C10.2, C11.2, C12.2, C13.2, C14.2, C15.2, C17.2, C18.2, C19.2, C20.2, C21.1, C22.2, C23.2, C24.1, C25.2, C26.2, C27.2, C28.1, C29.2, C30.2, D1.2 (A), D2.2 (A2), D3.1 (K), D4.1 (K), D5.1 (K), J1.6 (VSS), J1.SH (SHIELD), J2.8, J3.2, J4.3, J5.2, J6.2, J7.2, R1.1, R3.2, R4.2, R6.1, R9.2, R12.2, R13.2, SW1.1, U1.10 (VSS), U1.19 (VSSA), U1.26 (VSS), U1.49 (VSS), U1.74 (VSS), U1.99 (VSS), U2.7 (GND), U2.9 (GND), U3.2 (GND), U4.2 (RESV), U4.3 (RESV), U4.6 (GND), U4.7 (RESV), U4.9 (INT2/FSYNC/CLKIN), U4.10 (RESV), U4.11 (RESV), U5.3 (VSS), U5.5 (SDO), U5.8 (VSS), U5.9 (VSS), U6.2 (GND), USB1.13 (EH), USB1.14 (EH), USB1.A1B12 (GND), USB1.B1A12 (GND)
unnamed: C1.2, U1.48 (VCAP)
unnamed: C2.1, U1.73 (VCAP)
unnamed: C3.1, SW1.2
unnamed: C19.1, R7.2
unnamed: C16.2, D1.1 (K), L1.1, U2.8 (SW)
unnamed: D3.2 (A), R20.1
unnamed: D4.2 (A), R21.1
unnamed: D5.2 (A), R22.1
unnamed: R1.2, SW2.2, U1.94 (BOOT0)
unnamed: C3.2, U1.14 (NRST)
unnamed: R23.1, U1.34 (PB0)
unnamed: C23.1, R8.1, R9.1, U1.15 (PC0)
unnamed: C5.2, U1.12 (PH0), Y1.2
unnamed: C4.2, U1.13 (PH1), Y1.1
unnamed: C16.1, U2.1 (BOOT)
unnamed: C20.1, R7.1, U2.6 (COMP)
unnamed: R2.2, R3.1, U2.3 (EN)
unnamed: R5.2, R6.2, U2.5 (FB)
unnamed: R4.1, U2.4 (RT/CLK)
unnamed: R13.1, USB1.A5 (CC1)
unnamed: R12.1, USB1.B5 (CC2)

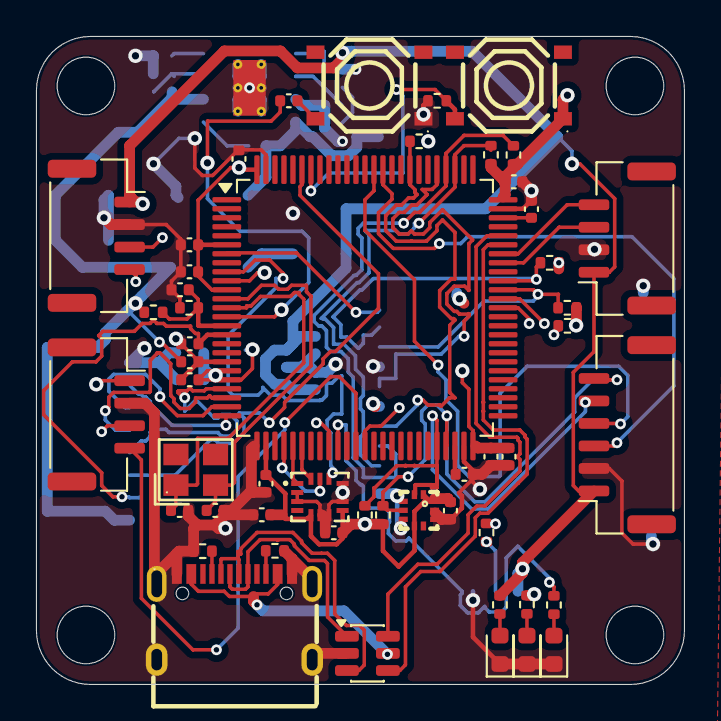
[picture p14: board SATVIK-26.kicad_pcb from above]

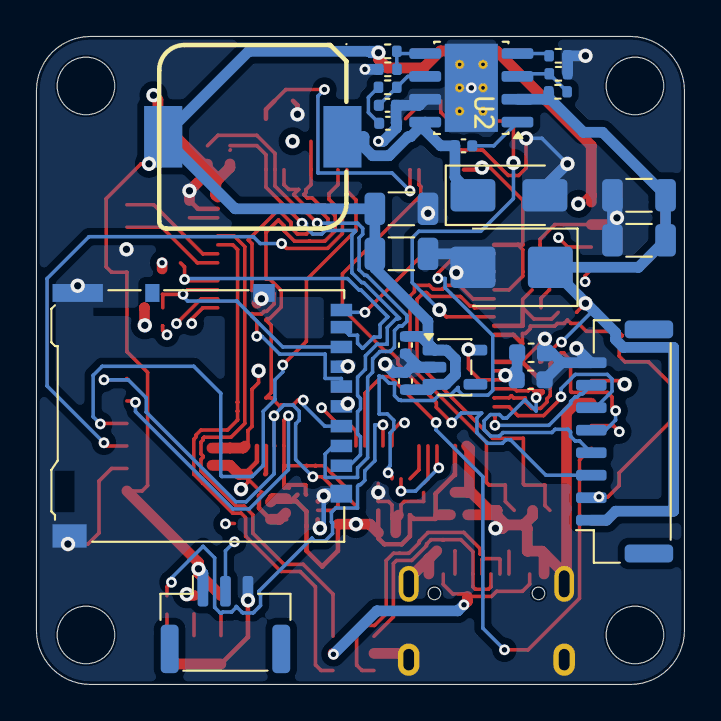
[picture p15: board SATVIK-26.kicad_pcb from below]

Board: 4 copper layers, 36.0 x 36.0 mm, 76 parts (25 on the bottom side), 59 nets.

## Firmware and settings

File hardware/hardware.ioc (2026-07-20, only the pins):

Mcu.UserName=STM32H743VITx
PA0.Signal=S_TIM5_CH1
PA1.Signal=S_TIM5_CH2
PA10.Signal=USART1_RX
PA11.Signal=USB_OTG_FS_DM
PA12.Signal=USB_OTG_FS_DP
PA2.Signal=S_TIM5_CH3
PA3.Signal=S_TIM5_CH4
PA5.Signal=SPI1_SCK
PA6.Signal=SPI1_MISO
PA7.Signal=SPI1_MOSI
PA9.Signal=USART1_TX
PB0.Signal=S_TIM3_CH3
PB1.Signal=S_TIM3_CH4
PB10.Signal=I2C2_SCL
PB11.Signal=I2C2_SDA
PB8.Signal=UART4_RX
PB9.Signal=UART4_TX
PC0.Signal=ADCx_INP10
PC1.Signal=ADCx_INP11
PC10.Signal=SDMMC1_D2
PC11.Signal=SDMMC1_D3
PC12.Signal=SDMMC1_CK
PC6.Signal=USART6_TX
PC7.Signal=USART6_RX
PC8.Signal=SDMMC1_D0
PC9.Signal=SDMMC1_D1
PD2.Signal=SDMMC1_CMD
PD5.Signal=USART2_TX
PD6.Signal=USART2_RX
PE7.Signal=UART7_RX
PE8.Signal=UART7_TX

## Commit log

2026-07-20 Cezual update
    [SATVIK-26.kicad_sch]
2026-07-20 couple hours
    [SATVIK-26.kicad_sch]
2026-07-20 Schematic Completed finally
    [SATVIK-26.kicad_sch]
2026-07-22 bruh
    tis shi is hard :)
    [SATVIK-26.kicad_sch]
2026-07-23 Hardware done!
    [BOM output latest-JLCPCB Assembly Order.xls, BOM output latest.csv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]
2026-07-23 Hardware completed!
    [BOM output latest-JLCPCB Assembly Order.xls, BOM output latest.csv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]
2026-07-23 Hardware update
    [BOM output latest-JLCPCB Assembly Order.xls, BOM output latest.csv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]
